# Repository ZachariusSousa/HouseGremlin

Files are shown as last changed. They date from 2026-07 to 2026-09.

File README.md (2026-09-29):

# HouseGremlin / Robit

Robit should be built as two cooperating codebases:

- **Robot firmware**: runs on the ESP board, drives motors/servos, exposes status/camera HTTP plus a persistent control socket, and stays responsive.
- **PC brain**: runs on your computer, handles camera streaming, LLM/tool calling, speech, logging, and higher-level autonomy.

Do not put vision or LLM work on the motor controller. Keep the robot firmware boring and real-time-ish; offload expensive work to the PC.

## Naming

- **HouseGremlin** = this repository / the overall project brand.
- **Robit** = the physical robot (firmware, mDNS `robit.local`, `ROBIT_*` env vars).

## Repo Layout

| Path | What it is | Runs standalone? |
|---|---|---|
| `brain/` | FastAPI PC service: talks to the robot, owns LLM/vision/speech/autonomy | needs robot + LLM |
| `tracking/` | RF-DETR Nano person-detector sidecar (port 8091) | needs GPU, no robot |
| `memory/` | SQLite knowledge graph + ingestion driver + web researcher (port 8092) | Python only |
| `web_control/` | Browser control panel (served by the brain) | — |
| `firmware/robit_controller/` | ESP32 firmware: motors, head, camera, control socket | on the robot |
| `Scripts/` | Cross-package glue: `supervisor.py`, `setup.bat`, `run.bat` | — |
| `cad/` | Printable model (Maindesign.stl) | — |
| `docs/architecture.md` | What talks to what, and why | — |

Port map: **8080** brain · **8081** llama-server (Gemma LLM) · **8091** tracking ·
**8092** memory · **8093** Bekko embeddings. Each package has its own `.venv`,
`requirements.txt`, and `.env.example`; start with the per-package README.

```text
                 ┌──────────────┐  TCP 82 (control)   ┌─────────────┐
 camera stream ─▶│    brain     │◀───────────────────▶│ Robit ESP32 │
   (from robot)  │    :8080     │                     │  firmware   │
                 └──┬───────┬───┘                     └─────────────┘
        HTTP 8091   │       │  OpenAI-compat 8081 / 8093
                    ▼       ▼
             ┌──────────┐  ┌──────────────────────────┐
             │ tracking │  │ llama-server (Gemma LLM) │ + Bekko embeds
             └──────────┘  └──────────────────────────┘
                 memory (:8092) is standalone — ingests brain telemetry,
                 runs the web researcher; nothing else depends on it.
```

`Scripts/supervisor.py` launches brain + tracking + both model servers together;
`memory/` runs on its own (`memory/.venv/Scripts/python -m memory.app.cli`).

## First Build Path

1. Flash `firmware/robit_controller/robit_controller.ino`.
2. Edit Wi-Fi credentials in `firmware/robit_controller/config.example.h`, save as `config.h`, and keep it private.
3. Deploy the matching Brain and confirm its `/robot/*` controls work.
4. Run the PC brain and point it at the robot IP.
5. Add camera streaming.
6. Add LLM tool calling against the PC brain API, not directly against the microcontroller.

## Windows Quick Start

Install 64-bit Python 3.13, then open PowerShell in this folder and run:

```powershell
.\setup
```

## Start

```powershell
.\run
```

When Robit is ready, open [http://localhost:8080](http://localhost:8080) to
use the control panel.

## Stop

Press `Ctrl+C` in the PowerShell window running Robit for a clean shutdown.
If an earlier stack was interrupted, run this from another PowerShell window:

```powershell
.\stop
```

## Robot interfaces

The firmware HTTP server exposes diagnostics and camera access only:

- `GET /status`
- `GET /api/status`
- `GET /camera`
- `GET /camera/capture`
- `GET /camera/stream` is a legacy alias for the still-capture endpoint on port `81`

Actuation uses protocol v1 on TCP port `82`. It is single-client, newline-delimited
JSON with a 512-byte limit, acknowledgements, TTL/sequence rejection, a one-second
PC heartbeat, and firmware telemetry. Direct ESP movement/head/eyes HTTP routes
were intentionally removed; use the stable Brain `/robot/*` API.

All camera acquisition is serialized and capped globally at 2 FPS
(`ROBIT_CAMERA_MAX_FPS=2`). The Brain shares one raw JPEG, rotated JPEG, and
preview for each frame. Idle acquisition is 0.2 FPS.

The XIAO ESP32S3 Sense camera page and still endpoint are:

```text
http://ROBOT_IP/camera
http://ROBOT_IP:81/capture
```

Current soldered pin assumptions:

- `D0` left forward, `D1` left reverse
- `D2` right forward, `D3` right reverse
- `D4` shared PWM for both motor-driver PWM inputs
- `D6`/`D7` PCA9685 servo I2C
- `D5`/`D8` reserved for the OLED eye I2C bus

## Brain

The PC service owns everything above the robot's HTTP/sockets layer: camera
capture and streaming, OpenAI-compatible LLM tool calling, realtime voice
(Parakeet STT / Qwen TTS sidecar), scripted behaviors, telemetry logging, and
the person-tracking controller that consumes `tracking/` detections.

See [docs/architecture.md](docs/architecture.md) for the current architecture and
[DESIGN.md](DESIGN.md) for the long-term Robit design roadmap.

Text and the language step in realtime Voice use one local Gemma 4 E4B
`llama-server`; structured Vision currently reuses it as well. Parakeet STT and
Qwen TTS remain separate voice models, and the Vision adapter remains replaceable
by a dedicated detector or VLM later. Install the validated shared environment
with:

```powershell
.\Scripts\setup.bat
```

The current Gate 5 surface is `GET /perception/latest` plus
`POST /perception/query`. Visual results are descriptive only and cannot issue
movement or head commands in the same turn.

RF-DETR Nano runs in its own `tracking\.venv`, so its Transformers 5
dependency cannot alter the validated voice environment. It powers one simple
always-on person tracker: Robit turns its head toward the visible person and
uses a delayed, bounded in-place body turn only when the head cannot keep up.
RF-DETR runs at 2 FPS while searching, 1 FPS on a stable target, and 0.5 FPS
during voice activity. Tracking starts with Robit and remains off only after an
explicit tracking stop. It does not replace semantic E4B scene descriptions and
it never retains routine camera frames. The tracking API is:

```text
GET  /tracking/status
POST /tracking/start
POST /tracking/stop
```

After `run.bat` is running, verify the default:

```powershell
Invoke-RestMethod http://localhost:8080/tracking/status
```

If tracking was explicitly stopped, turn it back on with:

```powershell
Invoke-RestMethod -Method Post `
  -Uri http://localhost:8080/tracking/start `
  -ContentType "application/json" `
  -Body '{}'
```

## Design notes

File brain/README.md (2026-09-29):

# Brain

This service runs on your computer and owns Robit's coordinator and safety layer: conversation state, event journaling, camera proxying, robot commands, typed and realtime LLM actions, arbitration, and logs.

The realtime speech server runs as a sidecar process, but it uses the same `brain\.venv` as the rest of the project.

## Prerequisites

- Python 3.13 for the shared `brain\.venv`
- `llama-server` from [llama.cpp](https://github.com/ggml-org/llama.cpp/releases) for the shared Gemma 4 E4B language backend
- NVIDIA GPU recommended for local realtime speech

## Run

From the repository root, run setup once:

```powershell
cd C:\Users\z1sou\HouseGremlin
Scripts\setup.bat
```

Then start Robit:

```powershell
Scripts\run.bat
```

The same setup command installs the validated dependencies used by voice and
structured vision. Vision reuses the realtime Gemma 4 E4B server; there is no
second vision-model download.

```powershell
.\Scripts\setup.bat
```

If omitted, `Scripts\run.bat` discovers Robit's current address from its mDNS
name, `robit.local`. This works independently of Windows' normal DNS resolver.

`setup.bat` creates one virtual environment at `brain\.venv` and installs both PC brain and realtime voice dependencies there.
`run.bat` invokes a supervisor that starts one two-slot Gemma 4 E4B `llama-server` for Text, the Voice
language step, and the current Vision adapter. It then starts the separate
Parakeet STT and Qwen TTS voice sidecar from the shared venv, starts the PC
brain in readiness order, and opens the browser UI. Failed sidecars restart up
to three times with bounded backoff. Rotating logs are stored in
`brain\data\logs`. Ollama is not required.

To test realtime voice without the browser:

```powershell
cd C:\Users\z1sou\HouseGremlin
Scripts\voice_test.bat
```

This starts the realtime sidecar, connects a terminal mic/speaker client to `ROBIT_REALTIME_WS_URL`, and exits with `Ctrl+C`.

Manual PC brain setup, if you need to debug it directly:

```powershell
cd C:\Users\z1sou\HouseGremlin\brain
py -3.13 -m venv .venv
.\.venv\Scripts\Activate.ps1
python -m pip install --upgrade pip
python -m pip install -r requirements.txt
```

Manual realtime sidecar run, if you need to debug it directly:

```powershell
cd C:\Users\z1sou\HouseGremlin\brain
.\.venv\Scripts\Activate.ps1
$env:OPENAI_API_KEY="local"
$env:OPENAI_BASE_URL="http://127.0.0.1:8081/v1"
llama-server -hf ggml-org/gemma-4-E4B-it-GGUF:Q4_0 --host 127.0.0.1 --port 8081 -np 2 -c 65536 -fa on --swa-full --reasoning off --image-max-tokens 140
```

In another PowerShell window:

```powershell
cd C:\Users\z1sou\HouseGremlin\brain
.\.venv\Scripts\Activate.ps1
$env:OPENAI_API_KEY="local"
$env:OPENAI_BASE_URL="http://127.0.0.1:8081/v1"
python -m speech_to_speech.s2s_pipeline --mode realtime --ws_host 0.0.0.0 --ws_port 7861 --stt parakeet-tdt --parakeet_tdt_model_name nvidia/parakeet-tdt-0.6b-v3 --parakeet_tdt_device cuda --parakeet_tdt_compute_type float16 --llm_backend responses-api --model_name ggml-org/gemma-4-E4B-it-GGUF:Q4_0 --responses_api_api_key local --responses_api_base_url http://127.0.0.1:8081/v1 --responses_api_request_timeout_s 180 --tts qwen3 --qwen3_tts_model_name Qwen/Qwen3-TTS-12Hz-1.7B-CustomVoice --qwen3_tts_device cuda --qwen3_tts_speaker serena
```

`run.bat` resolves `robit.local` through mDNS service discovery and passes the
current IP to the PC brain internally. Use a numeric argument only for recovery
or diagnostics.
Text mode, the language step in realtime Voice, and the current structured
Vision adapter share one `ggml-org/gemma-4-E4B-it-GGUF:Q4_0` llama.cpp process
at `http://127.0.0.1:8081/v1`. Voice still uses its own Parakeet STT and Qwen
TTS models. Vision remains behind `VisionService` and its own
`ROBIT_VISION_MODEL`/`ROBIT_VISION_BASE_URL` settings so it can move to a
dedicated detector or VLM later without changing Text or Voice.
LLM-issued movement defaults to `ROBIT_LLM_DEFAULT_SPEED=170`, is clamped by
`ROBIT_LLM_MAX_SPEED=180`, and is limited by `ROBIT_LLM_MAX_DURATION_MS=1000`.
The Brain is the only control producer. It connects to firmware protocol v1
on TCP port 82 and coalesces tracking head targets to at most 4 Hz. Manual head
control may run at 10 Hz and leases the actuators for three seconds before
tracking discards its old target and reacquires.

## Checks

From the repository root:

```powershell
.\brain\.venv\Scripts\python.exe -m compileall brain\app brain\tests
.\brain\.venv\Scripts\python.exe -m pytest brain\tests
```

From inside `brain`:

```powershell
python -m compileall app tests
python -m pytest tests
```

## Endpoints

- `GET /health`
- `GET /robot/status`
- `GET /robot/camera`
- `GET /robot/camera/capture`
- `GET /perception/latest`
- `POST /perception/query`
- `POST /robot/drive`
- `POST /robot/head`
- `POST /robot/stop`
- `POST /robot/action`
- `POST /chat`
- `POST /chat/action`
- `GET /brain/state`
- `GET /brain/events`
- `WS /v1/realtime`
- `GET /tools`

The realtime voice sidecar remains separate at `ROBIT_REALTIME_WS_URL`, defaulting to `ws://localhost:7861/v1/realtime`, but it is private to `brain`. The browser connects to the brain gateway at `WS /v1/realtime`.

## Operator Console

The console shows the shared low-rate robot camera, structured scene awareness,
robot telemetry, silent Text mode, realtime Voice mode, manual controls, and an
action log. Text mode calls `/chat/action`; Voice mode streams mic audio to
`brain`, which owns the sidecar session and executes `robot_action` and the
read-only `inspect_scene` tool server-side. Vision cannot authorize movement in
the same turn.

Quick endpoint checks:

```powershell
Invoke-RestMethod http://localhost:8080/health
Invoke-RestMethod http://localhost:8080/robot/status
Invoke-RestMethod http://localhost:8080/robot/camera
Invoke-RestMethod http://localhost:8080/brain/state
Invoke-RestMethod http://localhost:8080/perception/latest
Invoke-RestMethod http://localhost:8080/perception/query `
  -Method Post `
  -ContentType "application/json" `
  -Body '{"question":"What do you see?","fresh":true}'
Invoke-RestMethod "http://localhost:8080/brain/events?conversation_id=default&after_sequence=0&limit=100"
Invoke-WebRequest http://localhost:8080/robot/camera/capture -OutFile $env:TEMP\robit.jpg
Invoke-RestMethod http://localhost:8080/robot/action `
  -Method Post `
  -ContentType "application/json" `
  -Body '{"movement":{"direction":"forward","speed":120,"duration_ms":300}}'
```

Test silent typed chat/action:

```powershell
Invoke-RestMethod http://localhost:8080/chat/action `
  -Method Post `
  -ContentType "application/json" `
  -Body '{"text":"Say hello in one short sentence.","conversation_id":"default"}'
```

Capture Gate 1 realtime latency and GPU usage after the stack is ready:

```powershell
cd C:\Users\z1sou\HouseGremlin
.\brain\.venv\Scripts\python.exe .\Scripts\benchmark_gate1.py
```

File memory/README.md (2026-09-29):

# memory — knowledge-graph memory

SQLite-backed knowledge graph for HouseGremlin's autonomous agents: entity/fact
nodes, typed edges, provenance, FTS5 + optional-embedding hybrid search, and
LLM-routed retrieval with trace logging. The service runs on port **8092**
(ports: 8080=brain, 8081=llama-server, 8091=tracking, 8092=memory).

Phase history and design decisions: `TODO.md`, `Plan.md`. Repo-level rationale:
`DESIGN.md` → "Memory Design" (note the deliberate pivot from "RAG before
GraphRAG" for this component).

## Quickstart

```powershell
# from repo root C:\dev\HouseGremlin
.\memory\.venv\Scripts\python.exe -m pip install -r memory\requirements.txt

# tests (fully mocked LLM; no network, no live model)
.\memory\.venv\Scripts\python.exe -m pytest memory/tests -q

# seed the demo corpus (idempotent sky-is-blue causal chain + distractors)
.\memory\.venv\Scripts\python.exe -m memory.app.cli seed

# start the service on 8092
.\memory\.venv\Scripts\python.exe -m uvicorn memory.app.main:app --port 8092
```

If no embedding endpoint is reachable, the service degrades to FTS5-only mode
and `GET /health` reports `"embedding_mode": "fts5_only"`. If the chat LLM is
down, retrieval degrades to seed-only context with a warning; ingest endpoints
return 503.

## Service (port 8092)

| Endpoint | Body | Returns |
| --- | --- | --- |
| `GET /health` | — | `{"status": "ok", "embedding_mode": "hybrid" \| "fts5_only"}` |
| `GET /stats` | — | node/edge/provenance counts |
| `POST /facts` | `{text, confidence?, source_kind?, source_ref?}` | `{node_id, verdict}` (`duplicate` / `related` / `contradiction` / `new`) |
| `POST /ingest/text` | `{text, confidence?, source_kind?, source_ref?}` | extraction summary (all-or-nothing; 422 on invalid LLM output) |
| `POST /ingest/url` | `{url, confidence?}` | extraction summary (502 on fetch failure) |
| `POST /retrieve` | `{question, max_hops?, beam?}` | `{context, nodes[], trace_id, seed_ids, visited_ids, decisions, ...}` |
| `GET /traces/{id}` | — | full `retrieval_traces` row (seeds, per-hop decisions, rendered context) |

Every `POST /retrieve` writes a `retrieval_traces` row — training data for the
future learned router.

## Environment variables (`MEMORY_*`)

| Variable | Default | Meaning |
| --- | --- | --- |
| `MEMORY_PORT` | `8092` | service port |
| `MEMORY_DB_PATH` | `memory/data/memory.db` | SQLite path (relative paths resolve under `memory/`) |
| `MEMORY_LLM_BASE_URL` | `http://127.0.0.1:8081/v1` | OpenAI-compatible chat endpoint |
| `MEMORY_LLM_MODEL` | `ggml-org/gemma-4-E4B-it-GGUF:Q4_0` | model name passed to the LLM |
| `MEMORY_LLM_TIMEOUT` | `30.0` | per-request timeout (seconds) |
| `MEMORY_CONTEXT_BUDGET_CHARS` | `6000` | hard rendered-context budget; lowest-relevance nodes are dropped until under budget |
| `MEMORY_MAX_HOPS` | `3` | default hop-router depth |
| `MEMORY_BEAM` | `6` | default candidate beam width |

## Agent usage example

```powershell
# remember a fact (dedup/merge/contradiction judged by the LLM, never silent overwrite)
curl -s -X POST http://127.0.0.1:8092/facts -H 'Content-Type: application/json' `
  -d '{"text": "The greenhouse thermostat is on the north wall.", "source_kind": "agent", "source_ref": "conv-42"}'

# retrieve routed context for a question
curl -s -X POST http://127.0.0.1:8092/retrieve -H 'Content-Type: application/json' `
  -d '{"question": "why is the sky blue"}'
```

The `context` string is pre-rendered, budget-bounded text (node sentences with
edge-type annotations) safe to paste into a prompt. `nodes[]` carries ids,
kinds, and hop depths if you need structured access; `trace_id` links back to
the logged traversal.

## CLI walkthrough

All commands run as `.\memory\.venv\Scripts\python.exe -m memory.app.cli <cmd>`:

| Command | Purpose |
| --- | --- |
| `add-fact TEXT [--confidence F] [--source-kind K] [--source-ref R]` | add one canonical fact node with provenance |
| `ingest-text TEXT [--confidence F]` | LLM-extract triples/facts from raw text (all-or-nothing) |
| `ingest-url URL [--confidence F]` | web search + fetch + extract (per-URL cache, skip-and-continue) |
| `seed` | idempotently load the sky-is-blue demo corpus |
| `retrieve QUESTION [--max-hops N] [--beam N]` | routed retrieval; prints context + trace summary |
| `inspect NODE_ID` | show a node with its edges and provenance |
| `forget NODE_ID` | delete a node and cascade its edges/provenance/FTS rows |
| `stats` | node/edge/provenance counts |
| `health` | health + embedding mode |
| `rebuild` | re-sync the FTS5 index from source rows |
| `export-traces --out PATH [--format jsonl\|csv]` | export `retrieval_traces` for offline analysis/training |

## Retrieval model

1. **Seeds** — question tokens (stopwords filtered) hit the FTS5 external-content
   table; when embeddings are available, cosine-similar nodes are added. Both
   score lists are fused with reciprocal-rank fusion into top-k entrance nodes.
2. **Hop router** — up to `max_hops` (default 3) LLM hops: candidates are typed
   edge neighbors of the visited set plus embedding-similar unvisited nodes
   (beam ≤ 6). The LLM returns strict JSON: chosen candidate ids with one-line
   reasons, or `stop`.
3. **Context assembly** — visited nodes ordered by hop/relevance, rendered as
   compact text blocks, then trimmed from the lowest-relevance end until under
   `MEMORY_CONTEXT_BUDGET_CHARS` (hard budget).

Contradictory facts coexist: a `contradiction` verdict links both fact nodes
with `contradicted_by` edges and keeps both active — age never lowers
confidence.

## Evaluation groundwork

- `evals/questions.json` — 12 curated questions over the seed corpus (single-hop
  and multi-hop).
- `app/eval.py` — harness stub: scores returned context against expected key
  facts for LLM-router vs learned-router A/B. The learned side is a documented
  `NotImplementedError` placeholder until traces accumulate and a model is
  trained (`export-traces` feeds that pipeline).

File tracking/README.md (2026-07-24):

# Robit RF-DETR sidecar

This local-only service keeps RF-DETR and its Transformers 5 dependency out of
the voice environment. It accepts shared broker JPEGs and returns only `person`
detections. It does not retain images.

The default `ROBIT_TRACKING_DEVICE=auto` selects CUDA/BF16 when supported and
otherwise runs on CPU. Model-load failures leave the service available for
health checks while `/detect` returns a clear `503`.

To force CPU for one run from PowerShell:

```powershell
$env:ROBIT_TRACKING_DEVICE = "cpu"
.\Scripts\run.bat
```

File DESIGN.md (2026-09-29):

# Robit Future Design Roadmap

This document describes the long-term direction for Robit's brain, perception,
memory, personality, tools, and autonomy. It is intentionally forward-looking.
For the architecture that exists today, see
[`docs/architecture.md`](docs/architecture.md).

The roadmap uses capability gates instead of dates. Work should advance only
after the preceding capability is reliable enough to build on.

## Vision

Robit should grow into a small room-scale companion that can converse, notice
its surroundings, remember useful things, perform approved routines, wander
silently, and research difficult questions in the background.

The target is a hybrid system:

- The ESP remains a deterministic body controller for motors, servos, eyes,
  bounded movement, and disconnect watchdogs.
- A Windows home server is the authoritative brain for speech, perception,
  memory, planning, tools, and autonomy.
- Robit remains useful offline. Internet research is optional and explicit.
- A fast speaking model handles conversation while a larger thinking model
  handles slower planning and research.
- Vision produces a compact structured world state instead of sending a
  continuous stream of image tokens to the conversation model.
- MCP tools are mediated by permissions and policy rather than exposed directly
  to a model.

The current RTX 4090 Laptop GPU with 16 GB VRAM is the development and
benchmarking system. A dedicated always-on Windows server can be chosen later
from measured resource requirements.

## System Shape

```mermaid
flowchart LR
    Mic["Microphone / Wake Word"] --> Voice["VAD -> STT"]
    Camera["ESP Camera"] --> Perception["Frame Gate -> Semantic VLM"]
    UI["Operator Console"] --> Brain

    Voice --> Brain["brain Cognitive Runtime"]
    Perception --> World["Rolling World State"]
    World --> Brain

    Brain --> Speaker["Fast Speaker"]
    Brain --> Thinker["Background Thinker"]
    Brain --> Affect["Tiny Affect Model"]
    Brain <--> Memory["Events + Hybrid RAG"]
    Brain <--> Broker["MCP Capability Broker"]
    Brain --> Executive["Deterministic Executive"]

    Affect --> Eyes["Eye Animation Controller"]
    Speaker --> TTS["TTS"]
    Thinker --> Jobs["Durable Research Jobs"]
    Executive --> Policy["Action Policy + Arbitration"]
    Broker --> Policy
    Policy --> ESP["ESP Safety Layer"]
    ESP --> Body["Tracks / Head / Eyes"]
```

`brain` should remain a modular Python application while the system is
small. Its interfaces should be compatible with a later ROS 2 bridge, but ROS 2
should not be an early dependency.

## State and Arbitration

Do not model Robit with a single thinking/speaking flag. Maintain four related
state planes:

- **Conversation:** `idle`, `listening`, `formulating`, `speaking`, or
  `interrupted`.
- **Body activity:** `stationary`, `looking`, `wandering`, `executing_skill`, or
  `fault`.
- **Background jobs:** zero or more `queued`, `running`, `needs_input`,
  `completed`, `failed`, or `cancelled` tasks.
- **Affect:** a slow-changing mood plus a fast expression overlay.

This allows Robit to wander silently while research runs, stop when addressed,
acknowledge a difficult question immediately, and report the result later.

Arbitration priority is fixed:

1. Hardware faults, firmware watchdogs, and movement limits.
2. Active voice and user interruption.
3. User language responses.
4. Explicit visual requests.
5. RF target reacquisition.
6. Background awareness and follow-ups.
7. Idle curiosity and wandering.

Tracks should normally stop when Robit begins listening or speaking. Head and
eye gestures may continue. Internal reasoning is never automatically spoken.

## Model Roles

| Role | Initial direction | Output | Authority |
| --- | --- | --- | --- |
| Speaker | Keep `gemma4:e4b` initially | Short response, delegation request, proposed tool intent | No direct execution |
| Thinker | Benchmark a larger 16 GB-capable reasoning model | Sourced research artifact or multi-step plan | No audio or motor access |
| Affect | Start with a CPU-hosted tiny text model | Valence, arousal, stance, confidence | Eyes only |
| Vision | Reuse Gemma 4 E4B through local llama.cpp | Typed scene snapshot | No actuation |
| Executive | Deterministic Python behavior code | Approved skills and schedules | May request body actions through policy |
| Retrieval | Local embedding model plus lexical search | Ranked memory references | Read-only |

Model names other than the existing `gemma4:e4b` are candidates, not permanent
commitments. Each role should have a versioned evaluation set so a model is
changed only when a replacement measurably improves Robit's real workload.

### Speaker and thinker

The speaker owns latency, personality, turn-taking, and verbalization. It may
answer directly, request a safe tool, or delegate work. The thinker runs as a
background job and returns a sourced result to the cognitive runtime. It never
speaks or moves the robot directly.

When delegation is needed, Robit should acknowledge it in one short sentence,
continue normal interaction, and proactively report the result when it is ready.
The foreground speaker reformulates that result in Robit's normal voice.

### Affect and eyes

The affect model should receive the latest user utterance, Robit's planned
reply, the dialogue act, current cognitive state, and previous mood. Its output
is a bounded schema containing:

- mood label
- valence
- arousal
- confidence
- requested expression
- expression lifetime

It never receives motor, memory-write, or MCP authority. Operational truth wins
over emotion: listening, thinking, and fault states cannot be hidden
by a cheerful classification.

Firmware should own fixed animations such as `neutral`, `listening`,
`thinking`, `speaking`, `curious`, `pleased`, `excited`, `concerned`, `sleepy`,
`startled`, and `fault`. Mood changes slowly, expression overlays change
quickly, and hysteresis prevents flickering.

## Core Data Contracts

All model-produced control data should use constrained JSON schemas and Pydantic
validation. Invalid output is logged and rejected; it is never partially
executed.

- **`BrainEvent`:** ID, event type, timestamp, source, correlation ID, priority,
  and payload.
- **`CognitiveState`:** conversation state, body state, active goal,
  connectivity, safety state, affect, and attention target.
- **`AffectState`:** label, valence, arousal, confidence, expression, and expiry.
- **`SceneSnapshot`:** frame ID, observation time, summary, entities, bounding
  boxes, novelty, and uncertainty.
- **`TaskRecord`:** task kind, requester, status, progress, approval state,
  result reference, error, and timestamps.
- **`MemoryFact`:** subject, predicate, object, source event, confidence,
  visibility, timestamps, and optional expiry.
- **`ActionIntent`:** skill, arguments, reason, origin, deadline, risk tier, and
  approval requirement.
- **`ToolCapability`:** MCP server, tool, scopes, side effects, risk tier,
  timeout, and concurrency limit.

Existing endpoints should remain compatible while being routed through the
coordinator. The planned interface includes:

- `WS /v1/realtime`
- `GET /brain/state`
- `GET /brain/events`
- `GET /perception/latest`
- `GET /tasks`, `POST /tasks`, and `POST /tasks/{id}/cancel`
- `GET /memories`, `POST /memories`, and `DELETE /memories/{id}`
- `GET /approvals` and `POST /approvals/{id}/decision`
- `POST /robot/eyes`
- firmware `POST /api/eyes`

The browser should become a transport and visualization client. It should not
execute model-selected tools or hold MCP credentials.

## Memory Design

Robit should have four memory layers:

- **Working memory:** recent dialogue and current world state, expiring within
  minutes.
- **Episodic memory:** summarized interactions and notable events.
- **Semantic memory:** durable people, preferences, places, commitments, and
  facts.
- **Procedural memory:** reviewed routines and executable skills.

SQLite in WAL mode should be the source of truth for events, facts, entities,
relationships, tasks, approvals, and artifacts. SQLite FTS5 supplies lexical
retrieval. A local vector index supplies semantic retrieval and remains
rebuildable from the source records.

Retrieval should combine lexical score, vector similarity, recency, entity
filters, confidence, and visibility. Every durable memory must retain its
source. Robit should support natural and UI-driven inspection, correction,
forgetting, and export.

Start with one primary-owner profile. Unknown people receive guest behavior and
cannot retrieve private memories. Do not retain continuous camera footage;
store structured notable events and selected frames only when policy allows.

### RAG before GraphRAG

Begin with hybrid retrieval and typed entity/relationship tables. Add a graph
query path only when a curated multi-hop memory test shows hybrid retrieval
missing more than 20 percent of relational answers and a graph prototype
improves accuracy by at least 15 percentage points without adding more than
500 ms to foreground recall.

This keeps graph-shaped data available without paying the indexing and
debugging cost of a full GraphRAG pipeline before the memory corpus justifies it.

**Implemented substrate (2026-09): `memory`.** The first durable-memory
implementation deliberately pivots from pure RAG for this component: `memory`
stores entity/fact nodes with typed edges and provenance, retrieval enters via
hybrid FTS5 + embedding seeds fused by reciprocal-rank fusion, and a bounded LLM
hop router then walks the graph (≤3 hops, beam ≤6) under a hard rendered-context
budget. This is scoped GraphRAG-style traversal, not a full pipeline — no
community summaries, and every hop decision is logged to `retrieval_traces` so
the empirical test above can still be run: the curated multi-hop question set in
`memory/evals/` is scored against expected key facts by the A/B harness in
`memory/app/eval.py`, before or after a learned router replaces the LLM hop.
Gate 4's semantic layer builds on this substrate rather than re-deriving storage
and retrieval.

## Vision Design

The conversation model should not consume every camera frame. The perception
pipeline should:

1. Sample the camera at a low working rate.
2. Reject blurred, duplicate, and unchanged frames.
3. Invoke the VLM for novel frames, explicit visual questions, scheduled
   awareness checks, or executive requests.
4. Convert results into short-lived `SceneSnapshot` records.
5. Merge recent snapshots into a compact `WorldState`.
6. Give the speaker structured facts rather than raw image tokens.

Uncertainty must be explicit, and `unknown` is a valid result. The VLM may
describe and ground the scene but never issue movement commands.

The first evaluation should use 300 to 500 frames from the actual ESP camera
across lighting, blur, empty rooms, people, furniture, and floor obstacles.
Validate the shared Gemma 4 E4B server on grounding, hallucinations, useful
summaries, latency, voice coexistence, and schema compliance. Start at 140
visual tokens and try 70 if the 750 ms p95 target is missed; consider a separate
vision model only if E4B still fails latency or grounded accuracy.

RF-DETR is a Gate 5 follow-up for fast person geometry used by one always-on
person-tracking behavior. It complements rather than replaces the semantic VLM:
RF-DETR supplies short-lived boxes and track observations, while the VLM remains
responsible for scene meaning, explicit visual questions, and structured
`SceneSnapshot` records. The first detector integration stays deliberately
simple: select one configured backend at startup, process only the newest frame
at a bounded cadence, and report unavailable when that backend cannot run. It
does not poll VRAM, dynamically unload models, or switch models based on live
memory readings. Tracking starts with Robit and has no timeout: the head follows
the selected visible person, with short in-place body pivots only when horizontal
error remains large. It stops only on an explicit tracking request.

## MCP and Tool Policy

`brain` should act as the MCP host and capability broker. MCP servers are not
exposed directly to the speaker or thinker.

The first integration wave should cover:

- web research
- weather
- timers and reminders
- notes
- calendar read
- carefully scoped smart-home actions

Risk tiers:

- **Tier 0:** public read-only data; automatic.
- **Tier 1:** local, easily reversible actions such as timers or appending a
  note; automatic but logged.
- **Tier 2:** external writes, messages, calendar changes, or device changes;
  confirmation required.
- **Tier 3:** purchases, locks, deletion, credentials, or broad computer access;
  explicit per-action approval and optionally disabled.

Tool descriptions and results are untrusted data, not system instructions.
Credentials stay server-side and out of prompts, logs, and memory. Servers and
scopes are allowlisted. Every call has a timeout, concurrency limit, output-size
limit, audit event, and cancellation path.

Robit should own a durable internal task system. MCP task support can be adapted
at the protocol boundary without making the core job lifecycle depend on an
evolving external specification.

## Capability-Gated Roadmap

### Gate 0: Restore and measure the current baseline

**Status: functionally closed on 2026-07-14.**

The functional exit condition has been met: the repaired Python 3.11
environment passes all 18 tests, and the real browser UI has completed realtime
voice conversation plus bounded manual and model-requested robot actions. Camera,
text chat, action parsing, and movement safety clamps are working in the current
baseline.

The pan axis has a known mechanical stall under load. Commands reach the shared
manual/AI firmware path correctly, so this is accepted as a chassis or servo
design limitation for Gate 0 rather than an unresolved brain-stack failure. A
bounded-stop and disconnect-watchdog checks must be repeated after any motor,
power, or chassis revision.

- Recreate the stale Python 3.11 virtual environment with the existing setup
  script.
- Verify camera, text chat, realtime voice, manual movement, action parsing,
  safety clamps, ordinary stop, and disconnect stopping.
- Record warm and cold latency, CPU, VRAM, and failure logs for every model
  stage.
- Create a permanent evaluation corpus covering dialogue, tool calls,
  uncertainty, malformed output, interruption, and safety.

Exit when existing tests pass and the real browser UI completes one voice
conversation and one bounded robot action.

Carry the formal warm/cold latency, CPU, VRAM, failure-log capture, and permanent
evaluation corpus into the opening Gate 1 baseline work. These artifacts remain
required before making model or server sizing decisions, but they do not reopen
the functional Gate 0 baseline.

### Gate 1: Make `brain` authoritative

**Status: functionally closed on 2026-07-15.**

The coordinator, SQLite WAL event journal, state planes, correlation tracing,
priority arbitration, foreground resource lease, realtime gateway, reconnect
replay, and server-owned voice tool execution are implemented. The automated
suite passes 49 tests. Live gateway measurements reached first audio in 0.833
seconds on the first session turn and 0.337 seconds warm using `serena`.

The physical acceptance pass is complete. The real browser preserves the active
conversation across reconnects, bounded actions execute on the robot, and each
action can be traced back to its originating request through the shared event
and correlation flow.

- Add the event model, state planes, append-only journal, and priority arbiter.
- Put realtime session ownership behind `brain` while reusing the current
  VAD, STT, and TTS components.
- Move voice tool execution out of browser JavaScript.
- Give foreground work a resource lease that can preempt background GPU jobs.
- Use the same conversation, policy, memory, and event flow for Text and Voice
  modes.
- Carry correlation IDs from utterance through model, tool, firmware, and UI.

Exit when reconnecting the browser preserves the active conversation and every
robot action can be traced to its originating request.

### Gate 2: Implement eyes and affect

**Status: functionally closed on 2026-07-19.**

The physical eye renderer, automatic operational overlays, expression policy,
and heartbeat fault path are sufficient to build on. Affect-set validity,
heartbeat timing, and end-to-end voice/eye latency measurements remain tracked
as Gate 2 follow-up validation and do not reopen the functional gate.

**Early hardware bring-up:** the firmware began with a minimal SSD1306 wiring
test on the shared D6/D7 I2C bus at addresses `0x3C` and `0x3D`. At boot it
briefly illuminated every pixel and then displayed a thick horizontal line.
That test established display wiring and power before the Gate 2 renderer was
implemented.

The fixed expression renderer and firmware `/api/eyes` endpoint are implemented
and physically validated. `brain` now maintains a temporary LLM-selected base
mood beneath deterministic listening, thinking, speaking, and fault overlays.
Eye commands use a latest-value asynchronous queue, and an armed firmware
heartbeat watchdog displays `fault` after twelve seconds without the PC brain.

- Implement the fixed eye animations and firmware `/api/eyes` endpoint.
- Add the affect schema, tiny classifier, mood decay, expression overlays, and
  operational overrides.
- Collect classifications and corrections for later fine-tuning or distillation.
- If the affect model is unavailable, display truthful operational state without
  inventing emotion.

Exit when affect output is valid on at least 99.5 percent of the evaluation set,
never changes tools or movement, and remains visually stable during rapid turns.

### Gate 3: Add autonomous voice presence

**Status: intentionally deferred while Gate 5 vision is implemented.**

- Add a local `Robit` wake word followed by VAD and Parakeet STT.
- Keep room audio at the microphone source until activation.
- Add visible and physical privacy mute states.
- Support barge-in that cancels queued speech and returns to listening.
- Keep Text mode silent and Voice mode spoken.
- Keep internal thoughts and research progress out of spoken output.

Exit when false wakeups are acceptable over several hours of household audio,
barge-in silences playback within 250 ms, and mute prevents capture.

### Gate 4: Add durable hybrid memory

**Status: intentionally deferred while Gate 5 vision is implemented.**

- Implement the working, episodic, semantic, and procedural memory layers.
- Add provenance-aware memory extraction and hybrid retrieval.
- Add remember, inspect, correct, forget, export, and retention controls.
- Add owner/guest isolation.
- Make the vector index fully rebuildable from SQLite.

Exit when curated recall tests pass, forgetting removes all derived records, and
private memories never appear in guest context.

### Gate 5: Add structured vision

**Status: functionally available as of 2026-07-22; improvements and acceptance
work required before closure.**

The initial software path now includes a mutex-protected firmware-wide 3 FPS
camera ceiling, a shared in-memory PC frame broker, blur/change filtering,
low-rate idle awareness, and fresh read-only visual questions. The broker
returns to 0.2 FPS only while person tracking is explicitly disabled and no
conversation needs a fresh view. Routine camera frames are not retained. E4B
evaluation and physical acceptance remain before Gate 5 closure.

Observed limitations of the current shared-E4B approach:

- Fresh inference has taken about 2.6 seconds in live use, substantially above
  the 750 ms p95 exit target. Explicit questions therefore have a noticeable
  pause, and sharing E4B with foreground conversation remains a contention risk.
- Scene summaries are often generic or lack useful detail. Grounding accuracy,
  entity recall, and hallucination rate have not yet been measured on the
  Robit-camera corpus.
- E4B has produced truncated JSON at the configured output budget. Validation
  correctly rejects it, but the resulting cached fallback can make an answer
  appear stale and the required 99 percent schema-validity rate is unproven.
- Realtime dialogue previously allowed old assistant visual claims to outweigh
  a newer structured snapshot. Visual history is now excluded when a voice
  session is restored, and current snapshots explicitly override earlier scene
  descriptions, but this mitigation needs longer live testing.
- The speech sidecar begins speculative generation as soon as transcription
  completes, which previously let it narrate an inspection without executing
  one. Explicit visual questions now cancel that response, run a fresh
  inspection, and start a grounded response; this is correct but adds latency.
- The PC broker's default 0.2 FPS idle cadence reduces bandwidth and power, but
  a newly changed scene may take up to five seconds to reach ambient context.
  Explicit visual questions and active tracking may request fresher frames up
  to the firmware's global 3 FPS ceiling.
- Schema compliance, physical camera traffic, no-frame-retention behavior, and
  foreground voice responsiveness still need the documented corpus and
  concurrency acceptance runs.

- Implement camera sampling, blur/change filtering, VLM invocation, scene
  snapshots, and rolling world state.
- Validate the shared Gemma 4 E4B backend on the Robit-camera corpus.
- Allow explicit fresh visual queries when cached perception is stale.
- Prevent vision from entering the motor control loop.
- Add RF-DETR person observations for default-on head and body person tracking
  without replacing the VLM semantic lane.
- Keep detector scheduling static and bounded: one configured backend,
  latest-frame-wins processing, bounded detector requests, and no live VRAM
  monitor or dynamic model swapping.

Exit when the chosen VLM processes selected frames within 750 ms at p95 on the
development laptop, reaches at least 99 percent valid structured output, meets
the grounded-description quality target, and does not starve foreground voice.
RF-DETR follow-up acceptance is additional and does not weaken or replace these
semantic-vision exit conditions.

### Gate 6: Add the background thinker

- Introduce durable, cancellable research and planning jobs.
- Delegate when research is requested, current information is required, several
  tools are needed, or the speaker has low confidence.
- Require sourced artifacts with claims, uncertainty, and a speaker-ready
  summary.
- Deliver one proactive follow-up while respecting quiet hours.
- Preempt or pause background inference for foreground voice.

Exit when jobs survive restart, results are source-supported, follow-ups occur
once, and foreground latency remains within budget.

### Gate 7: Add MCP companion tools

- Implement the MCP host, server registry, capability normalization, risk
  policy, approval flow, audit log, and cancellation.
- Add the companion-basics integrations.
- Test prompt injection, credential leakage, confused-deputy behavior, SSRF,
  malicious tool output, and unavailable servers.

Exit when every high-risk mutation requires approval, secrets never enter model
context, and failed tools cannot destabilize conversation or autonomy.

### Gate 8: Add bounded silent autonomy

Initial code-defined skills:

- `look_around`
- `short_wander`
- `investigate_change`
- `greet_visible_person`
- `return_to_idle`
- `sleep`
- `stop`

The model chooses a goal or approved skill, not motor pulses. The executive
expands skills into short bounded actions. New speech, lost connectivity, stale
perception, model failure, ordinary stop, or lost control connectivity cancels motion.

Begin mapless in one controlled flat room at low speed. Gentle furniture contact
is acceptable for the current tiny chassis, but the robot must not roam
unattended near stairs, ledges, heaters, water, or entanglement hazards.

Exit after at least 100 supervised ten-minute trials with no movement surviving
a stop condition and no repeated runaway behavior.

### Gate 9: Build the always-on Windows brain

- Add one PowerShell supervisor with `setup`, `start`, `stop`, `status`,
  `doctor`, `benchmark`, `backup`, and `restore` commands.
- Supervise the brain, model servers, voice adapter, vector index, and MCP
  servers as native Windows processes.
- Add health checks, automatic restart, exact model manifests, backup, and
  restore.
- Test loss of internet, robot Wi-Fi, MCP services, individual model processes,
  and GPU availability.
- Size the future server from measured peak usage plus 30 percent headroom.
- Complete a 72-hour soak test.

Exit when the stack starts after reboot, recovers from individual failures,
remains useful offline, and needs no collection of manually managed terminals.

## Later Expansion Paths

- **Mapping and docking:** add battery telemetry and a visually identifiable
  dock after mapless roaming is reliable. Begin with a marker or beacon; use
  natural visual SLAM only if markers are unacceptable.
- **Onboard companion computer:** add one when wake-word privacy, network-loss
  behavior, or latency cannot be handled at the audio source and ESP layer.
- **GraphRAG:** enable only after the measured relational-recall trigger.
- **ROS 2:** adopt only when mapping, odometry, transforms, multiple sensor
  streams, or Nav2 justify it.
- **Vision-language-action models:** evaluate only after collecting a large
  teleoperation dataset for Robit's exact chassis. They remain behind the normal
  skill and safety layers.
- **Household profiles:** add opt-in voice or face identity after the
  single-owner memory system passes privacy and forgetting tests.
- **Memory consolidation:** use idle time for summarization, contradiction
  detection, fact merging, and decay without inventing memories.
- **Active perception:** allow small head or body adjustments to resolve visual
  uncertainty before asking the VLM again.
- **Learning from demonstration:** convert reviewed manual-control recordings
  into named deterministic skills.
- **Digital twin and replay:** replay events, snapshots, decisions, and firmware
  responses without moving the real robot.
- **Curiosity budget:** eventually add bounded novelty-seeking, social energy,
  and boredom while keeping them subordinate to quiet hours and safety.

## Acceptance Metrics

- Warm end-of-speech to first audio: at most 1.5 seconds at p95.
- Barge-in to playback silence: at most 250 ms.
- Model-proposed physical actions passing schema validation: 100 percent.
- High-risk MCP actions executed without approval: zero.
- Durable memories without provenance: zero.
- Autonomous motion continuing after disconnect or ordinary stop: zero.
- Background work delaying voice because it holds GPU resources: zero.
- Significant events traceable through a single correlation ID: 100 percent.

Maintain versioned evaluation packs for conversation, affect, perception,
memory, tools, research, autonomy, crash recovery, offline operation, and
long-duration resource stability.

## PowerShell Workflow

Run initial setup from the repository root. The setup script detects and
recreates a broken virtual environment:

```powershell
cd C:\Users\z1sou\HouseGremlin
.\Scripts\setup.bat
```

Start the current application with:

```powershell
cd C:\Users\z1sou\HouseGremlin
.\Scripts\run.bat
```

During implementation, use a second PowerShell window for tests and endpoint
checks:

```powershell
cd C:\Users\z1sou\HouseGremlin
.\brain\.venv\Scripts\python.exe -m pytest brain\tests
Invoke-RestMethod http://localhost:8080/health
```

After Gate 1, also inspect the planned coordinator state:

```powershell
Invoke-RestMethod http://localhost:8080/brain/state
```

By Gate 9, the intended operator workflow is:

```powershell
.\Scripts\robit.ps1 doctor
.\Scripts\robit.ps1 start
.\Scripts\robit.ps1 status
.\Scripts\robit.ps1 benchmark
```

These `robit.ps1` commands are part of the future implementation contract; the
script does not exist yet.

## Locked Decisions

- The ESP remains the safety-critical body controller.
- The home-server brain remains Windows-based.
- Core personality, voice, memory, and basic behavior work offline.
- Web research is opt-in.
- The current laptop is the development system; a dedicated server comes later.
- Early autonomy is camera-led, mapless, supervised, and limited to one room.
- `brain` remains modular Python and ROS-ready without adopting ROS 2 now.
- Memory supports one primary owner first and is useful by default with inspect,
  correct, forget, and export controls.
- A dedicated tiny affect model drives emotional eye behavior, with operational
  overrides.
- Mood changes slowly while expressions react quickly.
- Speaking and thinking models are separate.
- Research acknowledges immediately and follows up proactively.
- MCP uses risk-tiered approval.
- `gemma4:e4b` remains the speaker model until a Robit-specific evaluation
  demonstrates a better replacement.

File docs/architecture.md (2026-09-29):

# Robit Architecture

## Recommendation

Build Robit as a distributed system:

```text
Browser / phone
      |
      v
PC brain service  <---- camera / mic / speakers / LLM / tools
      |
      v
ESP robot firmware <---- motors / servos / sensors
```

The ESP should not do vision, LLM calls, speech, or long-running decision logic. It should only do deterministic hardware control and report status. Your PC has the CPU, memory, networking, and storage for everything else.

## Why This Split

The current sketch is a good proof of concept: it starts a Wi-Fi access point, serves a web page, drives the motors, and controls the pan/tilt head. The problem is that it mixes UI, networking, and hardware control in one file. That is fine for testing, but it will get painful once you add camera streaming, autonomous behaviors, and LLM tool calling.

The next version should keep firmware small:

- receive commands
- clamp unsafe values
- stop motors if commands stop arriving
- expose status
- optionally read simple sensors later

The PC brain should handle:

- camera stream ingestion
- object/person detection
- speech-to-text and text-to-speech
- LLM conversation state
- tool calling
- route planning or behavior scripts
- logs and debugging UI

## Networking

Support both modes:

1. **Station mode**: Robit joins your home/dev Wi-Fi. This is the normal mode when the PC brain controls it.
2. **Fallback access point**: Robit creates `Robit-Control` if it cannot join Wi-Fi. This is useful for setup and recovery.

The firmware scaffold implements that pattern.

## Control API

Keep the robot interfaces boring. HTTP is diagnostic-only:

```text
GET /status
GET /api/status
GET /camera
```

All actuation uses the single-client NDJSON protocol v1 socket on TCP port 82.
The PC `ActuatorBroker` is the only producer. Sequence, TTL, acknowledgement,
heartbeat, and telemetry handling live at this boundary; body commands never
replay after reconnect.

## Camera

The camera is the built-in XIAO ESP32S3 Sense camera. Firmware serializes all
`/capture` acquisition through one mutex and enforces a global 2 FPS ceiling.
The legacy `/stream` URL redirects to one still capture so it cannot monopolize
the firmware's small HTTP server. The PC brain's in-memory `FrameBroker` controls demand
independently: it defaults to 0.2 FPS while idle and raises the request rate only
when tracking or conversation needs a fresher view. Person tracking is enabled
by default, so the low idle rate applies only after tracking is explicitly
disabled. Each acquired frame is shared with the browser, detector, and
perception pipeline. Routine frames are never written to disk.

## Structured Vision

`VisionService` rotates camera frames into their displayed orientation, rejects
blurred or unchanged 160x120 previews, and runs background awareness no more
than once every 30 seconds while conversation is idle. Valid VLM JSON becomes
a short-lived `SceneSnapshot`; snapshots from the last minute form `WorldState`.
The service sends selected frames to the existing Gemma 4 E4B llama.cpp server,
requests JSON-schema output, and disables itself cleanly if `/v1/models` does
not advertise multimodal image support. The shared server runs with reasoning
disabled so short voice and scene responses do not spend their latency budget
on hidden reasoning tokens. Text and the Voice language step also use this one
two-slot E4B process; the audio pipeline still has separate Parakeet STT and Qwen
TTS models. Vision keeps an independent adapter and configuration boundary so a
dedicated VLM can replace E4B later without changing Text or Voice.

Text and Voice can request a fresh read-only inspection through the PC brain.
The latest unexpired validated snapshot is also injected into every Text and
Voice model turn as live visual context. Awareness refreshes that context when
the scene changes and carries it forward across pixel-equivalent frames without
rerunning the VLM.
The same turn cannot use a vision result for movement or head control. Ordinary
stop, bounded movement duration, and link-loss stopping remain available.
`GET /perception/latest` is the browser's
scene-state feed and `POST /perception/query` forces an explicit inspection.

Gate 5 is functionally available but not accepted as complete. Live testing has
shown roughly 2.6-second fresh-inference latency, generic scene descriptions,
occasional truncated structured output, and stale visual claims from realtime
dialogue history. The gateway now removes superseded visual dialogue when it
restores a session, makes current snapshots override earlier descriptions, and
cancels speculative speech before answering an explicit visual question from a
fresh validated result. These mitigations preserve correctness but do not solve
the remaining latency and description-quality limits. The broker's 0.2 FPS idle
default intentionally permits up to five seconds of ambient-view delay, while
active tracking or conversation can request fresher frames up to the firmware's
2 FPS ceiling. Corpus, schema-validity, voice-concurrency, physical traffic, and
retention acceptance tests remain required before the gate is closed.

### Companion Person Tracking

RF-DETR is a Gate 5 follow-up that adds fast person boxes and short-lived track
observations for one always-on behavior. Robit turns its head toward the selected
visible person and uses a proportional in-place body turn when horizontal error remains
large for 1.5 seconds. RF-DETR runs at 2 FPS while acquiring, 1 FPS while
stable, and 0.5 FPS during voice activity. The behavior starts with Robit and
stops only after an explicit tracking request. It is not a VLM replacement. The VLM
continues to answer semantic visual questions and produce `SceneSnapshot`
records; RF-DETR only supplies the geometry used by this deterministic behavior.

The first implementation intentionally avoids a VRAM monitor or dynamic model
swapping. One detector backend is selected from configuration at startup, one
latest-frame-wins worker runs at a bounded cadence, and detector request
timeouts report the detector unavailable cleanly if inference cannot keep up.
This keeps CPU-only community builds understandable and prevents
hardware-specific resource policy from entering the safety path.

The control API is deliberately small:

```text
GET  /tracking/status
POST /tracking/start       {}
POST /tracking/stop        {}
```

The browser exposes one enabled checkbox and one status line. The camera proxy
returns `X-Robit-Frame-Id`; its optional target overlay is drawn only when that
exact ID matches `target.frame_id` from tracking status. A stale box is therefore
never painted over a newer frame.

## LLM Tool Calling

The LLM should call PC-side tools like:

- `drive(move, duration_ms)`
- `set_head(pan, tilt)`
- `look_for(object_name)`
- `speak(text)`
- `stop()`

Those tools should call the robot API or local camera/speech modules. The LLM should not directly hit firmware endpoints; keep a safety layer in the PC brain.

## Memory Service (standalone)

`memory/` is a self-contained service on port **8092** — nothing else depends on it,
so it runs in its own venv and can be developed without the robot. It owns:

- **Knowledge graph** — SQLite entity/fact nodes, typed edges, provenance, FTS5 +
  optional Bekko-embedding hybrid search, LLM-routed retrieval with traces.
- **Ingestion driver** (`watch-brain`) — tails the brain's telemetry journal and
  extracts durable facts into the graph.
- **Web researcher** (`research` / `watch-research`) — LLM-driven BFS over the web,
  source-agnostic (ddgs), findings stored with provenance.

It calls the same local Gemma llama-server (8081) and Bekko embed server (8093)
the brain uses; see `memory/README.md` for the CLI and `memory/.env.example`.

## Safety Defaults

The firmware should:

- stop motors on boot
- stop motors on unknown command
- stop motors after a heartbeat timeout
- clamp servo angles
- clamp motor speed

The PC brain should:

- rate-limit movement commands
- prefer short movement durations
- expose a hard stop command
- log autonomous actions

## Build Roadmap

1. **Firmware cleanup**
   - Move credentials to `config.h`
   - Add `/status`
   - Add command timeout
   - Keep fallback AP mode

2. **Manual PC control**
   - Run `brain`
   - Proxy manual commands to the robot
   - Confirm drive/head controls work

3. **Vision**
   - Validate shared E4B p95 latency, schema compliance, and grounding
   - Verify that two llama.cpp slots preserve foreground voice responsiveness
   - Fall back from 140 to 70 visual tokens before considering another model

4. **Voice**
   - Add push-to-talk or wake-word later
   - Start with a simple text chat interface

5. **LLM tools**
   - Add a tool layer in the PC brain
   - Start with safe movement and head-control tools
   - Add vision query tools after camera is reliable

6. **Autonomy**
   - Add scripted behaviors first
   - Let the LLM choose among those scripts
   - Add guardrails before free-form movement

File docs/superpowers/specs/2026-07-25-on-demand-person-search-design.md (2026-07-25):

# On-Demand RF-DETR Person Search Design

## Summary

Replace continuous YuNet/RF-DETR tracking with one explicit, bounded command:
"look at me." Robit searches for at most ten seconds using RF-DETR, stops on
the first valid person detection, and remains facing that general direction
with his head at a fixed head-height pose.

This is a hard cleanup. YuNet, face landmarks, angular gaze correction,
detector comparison modes, and the continuous tracking controller are removed
rather than disabled.

## Behavior

The deterministic text and voice phrases "look at me" and "find me" start one
person search. Only one search may run at a time.

At the start of a search, Robit:

1. Cancels any previous search.
2. Commands the head to pan `90` and tilt `75`.
3. Waits for the head command to complete and for a fresh camera frame.
4. Runs RF-DETR once on that frame.

If RF-DETR returns any person at or above the configured person confidence,
the first returned person wins. Robit sends an ordinary stop command, remains
at the current body orientation and fixed head-height pose, and reports that
he found someone. He does not center the person, publish a corrective head
target, or continue tracking.

If no person is detected, Robit performs one `350` ms right pivot at speed
`140`, waits `500` ms after the bounded movement ends, obtains a frame captured
after settling, and tries RF-DETR again. This repeats until a person is found
or ten seconds have elapsed.

On timeout, Robit sends an ordinary stop command, leaves his head at the
head-height pose, and reports that he could not find anyone. Manual head,
drive, and stop commands cancel an active search before taking control.

## Architecture

### PC Brain

Replace `PersonTrackingService` with a small `PersonSearchService`. It owns
only:

- idle, positioning, detecting, turning, found, timed-out, cancelled, and
  faulted states;
- one active search task;
- the ten-second deadline;
- fresh-frame RF-DETR requests;
- bounded body pivots and settling;
- cancellation generation;
- compact status and command counters.

The service does not maintain a target between frames, estimate velocity,
associate people, predict motion, calculate gaze angles, or run a background
detection loop.

The existing frame broker remains the only source of robot-camera frames.
Search requests ask for a frame newer than the completed head or body command,
so a frame captured during movement cannot authorize success or another turn.

The actuator broker remains the only source of ESP commands. Search pivots use
bounded movement durations. An ordinary stop supersedes movement after a
detection, timeout, cancellation, or fault.

### Tracking Sidecar

The sidecar becomes RF-DETR person-only:

- remove YuNet initialization and inference;
- remove face model asset downloading;
- remove `shadow`, `face_only`, and `person_only` mode selection;
- remove face boxes and landmarks from the response schema;
- retain the existing JPEG request, frame identity checks, person confidence,
  queue timing, inference timing, backend status, and isolated RF-DETR
  dependency.

If OpenCV is no longer used anywhere in the sidecar after cleanup, remove its
dependency and model files.

### Commands and APIs

Deterministic text and realtime voice routing recognize "look at me" and "find
me" and invoke the same search operation. The model does not need to infer a
sequence of turns.

Expose:

- `POST /tracking/look-at-me` to start and await a search;
- `GET /tracking/status` for current state, elapsed time, remaining time,
  attempts, last detection confidence, last error, and command counts.

Remove `/tracking/start`. Keep `/tracking/stop` only as a cancellation alias
for an active search; it does not manage a persistent tracking mode. Existing
manual robot endpoints remain unchanged.

## Configuration

Keep only person-search settings:

- RF-DETR base URL and request timeout;
- person confidence;
- search timeout, default `10` seconds;
- head-height pan, default `90`;
- head-height tilt, default `75`;
- right-pivot speed, default `140`;
- pivot duration, default `350` ms;
- post-command settling interval, default `500` ms.

Remove YuNet confidence, minimum face size, detector mode, camera field of
view, angular gains, angular deadband, continuous detector cadences, face
association timers, and continuous pivot timers.

## Failures and Cancellation

A detector error, camera timeout, rejected actuator command, or control-channel
disconnect ends the search as `faulted`, sends an ordinary stop when the
control channel permits it, and reports the exception class and stage.

Cancellation is generation-based. Results from an older camera request,
detector request, head command, or turn cannot mutate the new search or issue
another actuator command.

Search confirmation is spoken only after the final stop acknowledgement.
Failures and timeouts are reported as failures or timeouts, never as success.

## Observability

Do not store image bytes. Journal one event for search start and one terminal
event for found, timeout, cancelled, or faulted. Each detection attempt emits
a bounded numeric sample containing frame ID, attempt number, person
count, best confidence, detector latency, camera latency, and current search
state.

Health reports RF-DETR availability and latency. Tracking status no longer
contains face geometry, angular calculations, estimator confidence, target
age, or shadow comparison statistics.

## Tests

Tests cover:

- head-height positioning precedes the first detection;
- the first fresh frame containing any person ends the search;
- detection at the edge of the frame causes no centering correction;
- a miss causes one bounded right pivot and a post-settling fresh frame;
- a person found after a pivot causes stop and no further turn;
- timeout occurs within the ten-second bound and stops movement;
- manual head, drive, and stop cancel the search;
- stale results from cancelled searches cannot issue commands;
- only one search runs at a time;
- detector, camera, actuator, and disconnect failures are reported accurately;
- no background detector requests occur while idle;
- the sidecar returns person-only results and has no YuNet/OpenCV model path;
- deterministic text and voice phrases invoke the same operation;
- status and journal samples contain no image bytes.

## Acceptance

From idle, saying "look at me" causes Robit to place his head at the configured
head height and search to the right. He stops on the first RF-DETR person
detection without attempting to center or follow that person. The operation
finishes within ten seconds, remains idle afterward, and sends no further
camera, detector, head, or body tracking commands until another explicit
search request.

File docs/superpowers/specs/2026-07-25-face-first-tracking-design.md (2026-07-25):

# Robit Face-First Tracking Design

## Summary

Replace RF-DETR as Robit's primary gaze sensor with OpenCV YuNet face
detection. YuNet runs on CPU against frames already supplied by the shared
camera broker and publishes face boxes plus five facial landmarks. The
tracking controller aims at the midpoint between the detected eyes rather than
estimating face height from a general person box.

RF-DETR remains temporarily available only as the shadow comparator and
configuration rollback during the trial. It does not participate in normal
face-first control. After YuNet passes physical acceptance, remove RF-DETR and
its PyTorch/CUDA sidecar dependencies. The existing vision-language model
remains responsible for semantic scene and object understanding.

The cutover is gated by a shadow evaluation on actual Robit camera frames.
YuNet is the selected candidate, but it must beat the current tracker on
detection retention, aim-point stability, false positives, latency, and compute
load before it is permitted to control the head.

## Goals

- Keep Robit's visual attention centered on a visible face.
- Reduce GPU contention and detector latency.
- Preserve calm gaze through brief occlusion or head turns.
- React calmly when a face is no longer visible instead of chasing a body.
- Avoid face recognition, identity embeddings, or stored biometric data.
- Keep all routine frames memory-only and use the shared frame broker.
- Preserve the browser-facing tracking API where practical.

## Non-Goals

- Recognizing who a person is.
- Inferring emotion, attention, or intent from facial landmarks.
- Replacing the vision-language model for object or scene understanding.
- Increasing robot camera acquisition above the existing 2 FPS ceiling.
- Allowing raw detector output to control actuators directly.
- Tracking a person whose face is not visible.
- Fine-tuning a face detector before the stock model is evaluated on Robit's
  camera.

## Model Selection

### Selected primary detector: OpenCV YuNet

YuNet is a small ONNX face detector supported by OpenCV's
`FaceDetectorYN`. It returns a face box, confidence, and five landmarks: both
eyes, nose tip, and both mouth corners. The published model is approximately
338 KB. Its paper reports 1.6 ms inference on an Intel i7-12700K at 320x320,
and the OpenCV model documentation describes detection support for faces around
10x10 through 300x300 pixels.

YuNet is preferred because Robit's source frames are low resolution and the
required output is a stable facial aim point. CPU execution also avoids
competing with speech and language/vision workloads on the GPU.

References:

- <https://docs.opencv.org/master/d0/dd4/tutorial_dnn_face.html>
- <https://github.com/opencv/opencv_zoo/tree/main/models/face_detection_yunet>
- <https://link.springer.com/article/10.1007/s11633-023-1423-y>

### Evaluated alternatives

- **MediaPipe BlazeFace:** viable runner-up with six facial points and a
  streaming mode, but its 128x128 detector input is less compelling for
  Robit's small faces. It remains the fallback candidate if YuNet underperforms
  on profile faces in the shadow evaluation.
- **SCRFD:** strong difficult-face accuracy, but the supplied InsightFace model
  weights have non-commercial-research licensing restrictions and add a larger
  runtime surface.
- **MediaPipe Pose Landmarker:** useful for body landmarks, but performs more
  work than gaze requires and is optimized around a sufficiently visible body.
- **RF-DETR Nano:** useful as the current-system shadow comparator, but not
  suited to facial gaze because it returns only general person boxes. It is not
  part of the accepted end-state architecture.

## Architecture

### Detector boundary

Keep detection isolated from PC Brain behind a local sidecar interface. The
sidecar receives a frame ID, capture timestamp, rotated JPEG bytes, and score
threshold. It returns:

```json
{
  "frame_id": "opaque-frame-id",
  "captured_at": "ISO-8601 timestamp",
  "backend": "opencv/yunet/cpu",
  "latency_ms": 4.2,
  "queue_ms": 0.1,
  "faces": [
    {
      "confidence": 0.94,
      "bounding_box": [0.30, 0.18, 0.58, 0.56],
      "right_eye": [0.38, 0.31],
      "left_eye": [0.50, 0.31],
      "nose": [0.44, 0.39],
      "right_mouth": [0.39, 0.47],
      "left_mouth": [0.49, 0.47]
    }
  ]
}
```

All coordinates are normalized to the rotated frame. Results for a different
frame ID or timestamp are rejected. The sidecar does not acquire camera frames,
retain images, recognize identities, or issue actuator commands.

The production detector interface is typed around faces rather than preserving
RF-DETR's person-only response. During the trial, the old RF-DETR adapter
remains isolated behind the existing interface solely for comparison and
rollback. No shared face/person abstraction is added to production merely to
support the temporary migration.

### Tracking controller

The tracking controller is the sole owner of target association, temporal
estimation, gaze publication, and body-pivot authorization.

For a face target:

1. Derive the measured gaze point from the midpoint between the two eye
   landmarks.
2. Reject malformed landmark geometry and faces below the configured minimum
   pixel size.
3. Acquire after two consistent detections within two seconds.
4. Associate by temporal position, box overlap, scale change, and predicted
   motion. Do not use face embeddings.
5. Require three consistently superior detections before switching faces.
6. Feed the gaze point into the existing bounded alpha-beta estimator.
7. Publish desired gaze through the actuator broker using the existing
   deadband, coalescing, and rate limits.

The detector never sends individual servo steps and never authorizes movement
by itself.

### Face-first state flow

The controller tracks both a state and a target source:

```text
face_searching
  -> face_acquiring
  -> face_tracking
  -> face_grace
  -> face_lost
```

- **face_searching:** YuNet runs at 2 FPS. No stale target can move the body.
- **face_acquiring:** two consistent face detections are required.
- **face_tracking:** YuNet runs at 2 FPS initially and may drop to 1 FPS after
  the gaze is stable. Face geometry is authoritative.
- **face_grace:** preserve the last reasonable gaze for up to 2.5 seconds.
  Prediction is capped at 0.5 seconds and does not count as a detection.
- **face_lost:** after the grace period, discard the target and continue YuNet
  searching at 2 FPS without body movement.
- When the face detector returns two consistent observations, face tracking
  reacquires from fresh geometry and discards the old estimator state.
- After five seconds without a face, issue one neutral head target and remain
  in face searching without repeated head or body search movement.

Frames captured during a pivot or settling interval update neither the
face-gaze estimator nor body-movement authorization. The next post-settling
frame establishes a new screen-space estimate.

### Workload behavior

- YuNet runs on CPU and is outside the GPU workload queue.
- RF-DETR runs only during controlled shadow evaluation. It is disabled in
  face-control mode and removed after acceptance.
- Active voice does not need to pause or reduce YuNet.
- Explicit VLM requests retain their existing workload priority and consume the
  latest shared frame rather than opening a new camera poller.
- Only one rotated JPEG variant is produced for both detectors.

## Failure Handling

- If YuNet fails to load, tracking reports unavailable, holds no stale target,
  and returns to neutral without body searching.
- Detector timeouts contain the detector name, exception class, stage, frame
  ID, queue time, and inference time.
- Stale results are logged and ignored.
- Invalid landmark geometry is treated as a missed face, not as a controller
  fault.
- Reconnection never replays a gaze or body command derived from an expired
  frame.

## Public Status and Observability

Extend `/tracking/status` with:

- `target_source`: `face` or `none`
- `face_box`, normalized landmark coordinates, and face confidence
- face target age and estimator confidence
- YuNet cadence, queue latency, and inference latency
- trial mode and shadow-comparator health while shadow mode is enabled
- counts for face acquisitions, face losses, head commands, pivots, stale
  results, and invalid landmarks

At 1 Hz, `tracking.sample` records normalized face geometry, association
result, desired/actual head position, and detector timing. Routine image bytes
are never journaled.

## Shadow Evaluation

Before YuNet can control actuators, run it in shadow mode alongside the current
tracker on 300 to 500 real Robit frames. Include:

- frontal, profile, looking down, and briefly occluded faces
- near, typical-room, and far distances
- seated and standing positions
- bright, dim, and backlit scenes
- a second person entering and crossing the frame
- empty-room and face-like-object negative scenes
- frames immediately before and after head or body movement

YuNet and BlazeFace full-range may both be evaluated in the same harness. No
shadow detector result may issue an actuator command.

## Acceptance Criteria

YuNet becomes the primary detector only if the Robit-camera evaluation shows:

- at least 95% face retention after acquisition while a usable face remains
  visible
- reacquisition within two detector frames after a face returns
- fewer than 1% false-positive frames in the negative set and no persistent
  false target lasting two frames
- normalized eye-midpoint jitter below 0.03 p95 for a stationary person
- CPU inference latency below 20 ms p95 at the production frame size
- no GPU allocation by the face detector process
- no additional robot camera requests beyond the shared 2 FPS ceiling
- no more than four tracking head targets per second
- no body pivot while a stable face is centered
- no duplicate pivot caused by pre-pivot estimator state

The physical acceptance run must then retain a stationary face at least 95% of
the time for ten minutes and complete a thirty-minute voice-plus-tracking run
without camera, detector, or control-channel failure.

If YuNet misses the thresholds but BlazeFace passes them, BlazeFace becomes the
primary face detector without changing the controller contract. If neither
passes, roll back to RF-DETR and collect failure-specific frames before
considering fine-tuning.

## Rollout and Rollback

Introduce a configuration-selectable detector mode:

- `shadow`: current RF-DETR control with YuNet measurement only
- `face_only`: YuNet control with calm hold-and-neutral loss behavior
- `person_only`: previous RF-DETR behavior for rollback

Rollout proceeds from shadow evaluation to an attended ten-minute physical
test, then the thirty-minute mixed workload test. A configuration rollback must
not require firmware changes during the trial.

After YuNet passes acceptance:

- remove `person_only` and the RF-DETR sidecar from normal startup
- remove RF-DETR, PyTorch, Transformers, and detector-specific CUDA
  dependencies from `pc_tracking`
- rename the remaining sidecar and status text from RF-DETR tracking to face
  tracking
- retain the last accepted RF-DETR release in version control as the rollback
  boundary instead of carrying its runtime dependencies indefinitely

The trial temporarily adds `opencv-python-headless` and the YuNet ONNX model.
The accepted end state replaces the RF-DETR dependency stack rather than
adding another permanent detector stack.

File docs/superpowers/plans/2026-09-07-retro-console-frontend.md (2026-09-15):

# Restore Full Robit Console Functionality Plan

> **For agentic workers:** REQUIRED SUB-SKILL: Use superpowers:subagent-driven-development (recommended) or superpowers:executing-plans to implement this plan task-by-task.

**Goal:** Integrate camera, tracking, voice, chat, telemetry, memory, diagnostics, and manual robot controls into the approved RB-01 retro-anime HUD.

**Architecture:** Keep `web_control/index.html` as a dependency-free single-file client served by FastAPI. Six in-page subsystem screens share one browser state model and the existing HTTP/WebSocket interfaces; no backend schemas change.

**Tech Stack:** HTML5, CSS, browser JavaScript, FastAPI, pytest.

**Spec:** User-approved restore plan from 2026-09-07.

## Global Constraints

- Preserve the approved CRT console shell and visual grammar.
- Camera starts automatically; tracking requires explicit activation.
- Voice requires an explicit connect gesture and uses the brain WebSocket gateway.
- Manual control uses a simple session-local arm toggle and always stops on release/disarm.
- Browser-side voice tools and `/tracking/approach` remain absent.

---

### Task 1: Restore the browser contract

- [x] Add failing contract assertions for every required endpoint, frame matching, voice capture, control disarm, and six mode panels.
- [x] Confirm the approved static mock fails the operational contract.
- [x] Retain the visual identity assertions.

### Task 2: Build the six live subsystem screens

- [x] Preserve Overview and add separate Optical, Manual, Voice, Memory, and Diagnostic workspaces.
- [x] Make F1-F6 and the mode buttons switch exactly one workspace at a time.
- [x] Prevent decorative overlays from intercepting navigation.
- [x] Replace Overview's fictional subsystem indicators with live state summaries.

### Task 3: Restore camera, tracking, and perception

- [x] Restore low-rate camera capture, frame headers, object URL lifecycle, and visibility-aware polling.
- [x] Restore frame-matched normalized bounding boxes and tracking telemetry.
- [x] Keep tracking off until explicit start and expose explicit stop.
- [x] Restore perception summary and entities.

### Task 4: Restore control, chat, voice, memory, and diagnostics

- [x] Restore arm-gated drive and head commands with queued requests and automatic stop behavior.
- [x] Connect both emergency-stop controls to `/robot/stop` and disarm the UI.
- [x] Restore text chat and conversation rendering.
- [x] Restore realtime microphone capture, PCM16 streaming, transcript events, playback, and reconnect cleanup.
- [x] Restore read-only memory and action journal views.
- [x] Restore structured diagnostic refresh and reconnect controls.

### Task 5: Verify

- [x] Validate JavaScript syntax and static operational contracts.
- [x] Exercise all mode controls at the rendered desktop viewport with no horizontal overflow.
- [x] Verify camera, frame-matched overlay, tracking, chat, drive, release-stop, head, emergency stop, memory, and diagnostics against a mock brain.
- [ ] Run pytest after restoring the repository's broken Python 3.11 virtual environment.
- [ ] Run hardware-in-the-loop checks through `Scripts\run.bat` when Robit is available.

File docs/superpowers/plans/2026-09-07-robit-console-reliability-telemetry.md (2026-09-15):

# Robit Console Reliability and Telemetry Repair

## Goal

Repair the frontend as one cohesive monitoring-and-control console. Overview owns the sole live video and tracking overlay, F2 becomes Telemetry, every displayed value has a real source, LLM failures are observable, and X eyes appear only for a currently active critical robot-control fault.

## Global Constraints

- Preserve the retro visual language, six-key navigation, existing public control/chat routes, the 12-second ESP heartbeat watchdog, and compatibility with older firmware telemetry.
- Keep `/health.ok` as PC-process liveness, add truthful readiness/components, and never infer robot or LLM readiness from configuration alone.
- Poll browser telemetry once per second only while visible and retain 60 samples in memory; do not persist one-second telemetry.
- Report unsupported or missing measurements as `null`/`N/A`; never invent values or expose secrets.
- Execute no movement from malformed or unvalidated LLM output.
- Use tests first and preserve all unrelated user changes.

## Task 1: Fault lifecycle and canonical robot status

- Replace the persisted global safety latch with an active fault registry containing source, severity, message, and timestamp.
- Do not reactivate journaled transient faults at startup. Only critical actuation, ESP-watchdog, or confirmed robot-control faults force X eyes; LLM, voice, camera, and tracking failures are degraded services.
- Clear source-specific faults on recovery and send an immediate heartbeat/current desired state after reconnect.
- Normalize TCP, HTTP, and cached robot status into one non-blocking shape with source and age. Use online at <=3 seconds, stale at >3 through 15 seconds, offline after 15 seconds/disconnect, and fault for an active critical robot fault.
- Expose actual/requested eyes and the active override reason.
- Add red/green tests for restart, fault priority/recovery, noncritical degradation, transport normalization, freshness thresholds, and non-blocking cached status.

## Task 2: System telemetry and truthful readiness

- Add `GET /system/telemetry` with `host`, `llm`, `robot`, `tracking`, and active `faults` sections.
- Sample host CPU/RAM/process CPU and RSS, event-loop lag, network totals/rates, and optional NVIDIA GPU utilization/VRAM using a bounded `nvidia-smi` call.
- Explicitly pin psutil. Unsupported GPU collection returns structured unavailable data without failing the endpoint.
- Keep `/health.ok` as liveness and add `ready` plus per-component status, reason, latency, and check time.
- Probe LLM `/v1/models` on startup and every 10 seconds without token generation; track last inference latency/result.
- Add red/green tests for sampler deltas, counter reset, unavailable GPU, telemetry shape, readiness truth, and stale component state.

## Task 3: Reliable LLM action output

- Use the existing action Pydantic model as strict JSON Schema for `/chat/action`, matching the working vision pattern.
- Retry once without `response_format` only when a provider rejects that capability, while retaining identical Pydantic validation.
- Surface warm-up/probe failures rather than swallowing them and record request outcome/latency.
- Never execute invalid output.
- Add red/green tests for schema request, unsupported-schema fallback, valid action, malformed output, timeout, and recovery.

## Task 4: ESP32 telemetry extension

- Add bounded additive telemetry for uptime, Wi-Fi mode/RSSI, heap and minimum heap, total heap, PSRAM free/total, camera state, and heartbeat armed/fault flags.
- Preserve protocol size and old-client compatibility; do not change the watchdog safety behavior.
- Update PC normalization tests with both old and new packets. Hardware compile/flash and watchdog validation remain manual if no CLI is available.

## Task 5: Frontend rebuild

- Move the sole real camera and frame-matched tracking overlay into Overview with retry, tracking toggle, scene summary, and entities.
- Repurpose F2 Optical as Telemetry. Move overview-only wires/stamp/registration into the Overview panel.
- Replace hard-coded 73% with real GPU VRAM percentage or N/A. Replace the static plot with a rolling 60-second RX/TX graph and add robot RTT history on Telemetry.
- Present PC/LLM metrics separately from ESP metrics, including explicit loading/unknown/stale/offline/fault labels.
- Poll `/system/telemetry` at 1 Hz while visible, immediately refresh on visibility regain, and cap histories at 60 samples.
- Add chat pending/elapsed/error/retry behavior, disable duplicate sends, and guarantee WebSocket errors leave Connecting state.
- Add red/green frontend contract tests and verify extracted JavaScript with Node plus browser interactions across all tabs.

## Task 6: Integrated verification

- Run all Python suites, frontend syntax/contract tests, endpoint smoke checks, and browser checks.
- Verify exact acceptance requirements against the approved plan.
- Record unavailable hardware-only checks explicitly; do not claim them complete without an ESP flash and controlled heartbeat test.

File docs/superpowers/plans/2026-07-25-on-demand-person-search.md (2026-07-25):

# On-Demand RF-DETR Person Search Implementation Plan

> **For agentic workers:** REQUIRED SUB-SKILL: Use superpowers:subagent-driven-development (recommended) or superpowers:executing-plans to implement this plan task-by-task. Steps use checkbox (`- [ ]`) syntax for tracking.

**Goal:** Remove YuNet and continuous tracking, replacing them with a ten-second RF-DETR-only command that turns right until the first person is visible.

**Architecture:** A compact `PersonSearchService` owns one explicit finite search operation and is idle otherwise. It positions the head once, alternates fresh RF-DETR checks with bounded right pivots, and terminates on the first person, timeout, cancellation, or fault. The tracking sidecar returns only RF-DETR person detections.

**Tech Stack:** Python 3.11, asyncio, FastAPI/Pydantic, HTTPX, RF-DETR, existing frame and actuator brokers, pytest/AnyIO.

## Global Constraints

- Search is explicit only; no idle/background detector loop remains.
- Search timeout is `10` seconds.
- Head-height pose is pan `90`, tilt `75`.
- Each miss authorizes one right pivot at speed `140` for `350` ms.
- Wait `500` ms after the bounded movement ends before capturing.
- The first RF-DETR person at or above configured confidence ends the search.
- Do not center, associate, estimate, predict, or follow a detected person.
- Manual head, drive, and stop cancel the active search.
- Stale results from a cancelled generation cannot issue actuator commands.
- Routine image bytes remain memory-only.
- Preserve the existing persistent ESP control channel and browser robot APIs.
- Stage only files named by the active task because the worktree contains prior reliability changes.

## File Structure

- `pc_tracking/app/main.py`: RF-DETR-only sidecar and person-only response schema.
- `pc_tracking/app/yunet.py`: delete.
- `pc_tracking/app/model_assets.py`: delete.
- `pc_tracking/requirements.txt`: remove OpenCV.
- `pc_tracking/tests/test_main.py`: RF-DETR-only API/backend tests.
- `pc_tracking/tests/test_yunet.py`: delete.
- `pc_tracking/tests/test_model_assets.py`: delete.
- `pc_brain/app/tracking.py`: replace temporal tracker with detector client and `PersonSearchService`.
- `pc_brain/app/config.py`: retain only search configuration.
- `pc_brain/app/main.py`: construct search service, route commands, cancel on manual actions, and expose search APIs/status.
- `pc_brain/tests/test_tracking.py`: focused person-search state, freshness, timeout, cancellation, and failure tests.
- `pc_brain/tests/test_tracking_temporal.py`: delete.
- `pc_brain/tests/test_config.py`: search defaults/validation and removed-mode regression.
- `pc_brain/tests/test_main_endpoints.py`: endpoint, deterministic text, and manual cancellation tests.
- `README.md`, `docs/architecture.md`, `pc_brain/README.md`, `pc_brain/.env.example`, `pc_tracking/README.md`: remove YuNet/continuous tracking documentation and describe the one-shot command.

---

### Task 1: RF-DETR-Only Tracking Sidecar

**Files:**
- Modify: `pc_tracking/app/main.py`
- Modify: `pc_tracking/requirements.txt`
- Modify: `pc_tracking/tests/test_main.py`
- Delete: `pc_tracking/app/yunet.py`
- Delete: `pc_tracking/app/model_assets.py`
- Delete: `pc_tracking/tests/test_yunet.py`
- Delete: `pc_tracking/tests/test_model_assets.py`

**Interfaces:**
- Produces: `RFDetrBackend.detect(jpeg: bytes, threshold: float) -> tuple[list[PersonDetection], float]`.
- Produces: `POST /detect` response with `frame_id`, `captured_at`, `model`, `backend`, `latency_ms`, `queue_ms`, `request_bytes`, and `people`.
- Removes: face fields, detector modes, YuNet model loading, and minimum-face-size header.

- [ ] **Step 1: Rewrite sidecar tests to require person-only behavior**

Add literal tests asserting:

```python
def test_health_is_rfdetr_only(monkeypatch):
    monkeypatch.setattr(main, "backend", FakeBackend())
    payload = TestClient(main.app).get("/health").json()
    assert payload["model"] == "Roboflow/rf-detr-nano"
    assert "face" not in payload
    assert "detector_mode" not in payload

def test_detect_returns_only_people(monkeypatch):
    monkeypatch.setattr(main, "backend", FakeBackend(
        people=[PersonDetection(confidence=0.8, bounding_box=(0.1, 0.1, 0.4, 0.9))]
    ))
    response = TestClient(main.app).post(
        "/detect",
        content=b"jpeg",
        headers={
            "X-Robit-Frame-Id": "frame-1",
            "X-Robit-Captured-At": "2026-07-25T00:00:00Z",
            "X-Robit-Threshold": "0.4",
        },
    )
    assert response.status_code == 200
    assert len(response.json()["people"]) == 1
    assert "faces" not in response.json()
```

Also retain device selection, unavailable backend, serialized inference, empty-body, normalized-box, and frame metadata tests.

- [ ] **Step 2: Run the sidecar tests to verify RED**

Run in PowerShell:

```powershell
cd C:\Users\z1sou\HouseGremlin
.\pc_tracking\.venv\Scripts\python.exe -m pytest pc_tracking\tests\test_main.py -q
```

Expected: failures because health and detection responses still expose YuNet/mode fields.

- [ ] **Step 3: Collapse `pc_tracking/app/main.py` to RF-DETR only**

Delete `TrackingBackend`, `DetectionBatch`, `DetectorMode`, face imports, and face constants. Instantiate:

```python
backend = RFDetrBackend()
```

Define the response as:

```python
class DetectionResponse(BaseModel):
    frame_id: str
    captured_at: str
    model: str = MODEL_NAME
    backend: str
    latency_ms: float
    queue_ms: float = 0.0
    request_bytes: int = 0
    people: list[PersonDetection] = Field(default_factory=list)
```

Run `backend.detect(jpeg, x_robit_threshold)` in `asyncio.to_thread`, preserve the inference lock and metrics, and expose only RF-DETR status from `/health`.

- [ ] **Step 4: Delete YuNet code/tests and remove OpenCV**

Delete the four YuNet/model-asset files listed above. Remove:

```text
opencv-python-headless==4.12.0.88
```

from `pc_tracking/requirements.txt`.

- [ ] **Step 5: Verify the sidecar**

```powershell
cd C:\Users\z1sou\HouseGremlin
.\pc_tracking\.venv\Scripts\python.exe -m compileall -q pc_tracking\app pc_tracking\tests
.\pc_tracking\.venv\Scripts\python.exe -m pytest pc_tracking\tests -q
```

Expected: compile exits zero and all remaining sidecar tests pass.

### Task 2: Bounded Person Search Service

**Files:**
- Replace: `pc_brain/app/tracking.py`
- Replace: `pc_brain/tests/test_tracking.py`
- Delete: `pc_brain/tests/test_tracking_temporal.py`

**Interfaces:**
- Produces: `PersonCandidate`, `DetectorResult`, and `RFDetrClient`.
- Produces: `PersonSearchStatus`.
- Produces: `PersonSearchService.search()`, `cancel(reason)`, `cancel_now(reason)`, `status()`, `motion_authorized(generation, body)`, `start()`, and `shutdown()`.
- Consumes: `FrameBroker.get_rotated_jpeg(degrees, force_fresh=True)`.
- Consumes callbacks:
  `head_command(pan, tilt, generation)`,
  `move_command(direction, speed, duration_ms, generation)`, and
  `stop_command(generation)`.

- [ ] **Step 1: Write the bounded-search tests**

Use a fake clock/frame broker/detector and command recorders. Cover these exact sequences:

```python
await service.search()
assert commands[:2] == [("head", 90, 75), ("stop",)]
assert detector.frames == ["fresh-after-head"]
assert service.status().state == "found"
```

For an initial miss then detection:

```python
assert commands == [
    ("head", 90, 75),
    ("move", "right", 140, 350),
    ("stop",),
]
assert detector.frames == ["after-head", "after-settling"]
```

Also assert edge-of-frame detection produces no head/body correction, timeout is bounded, cancellation invalidates a delayed detector result, duplicate callers share one search, manual cancellation stops future commands, idle performs no detection, and detector/camera/actuator errors yield `faulted` with stage and exception class.

- [ ] **Step 2: Run focused tests to verify RED**

```powershell
cd C:\Users\z1sou\HouseGremlin
.\pc_brain\.venv\Scripts\python.exe -m pytest pc_brain\tests\test_tracking.py -q
```

Expected: imports and behavior fail because `PersonSearchService` does not exist.

- [ ] **Step 3: Replace temporal types with compact person-only models**

Keep normalized person box validation and detector frame/capture identity checks:

```python
class PersonCandidate(BaseModel):
    confidence: float = Field(ge=0.0, le=1.0)
    bounding_box: tuple[float, float, float, float]

class DetectorResult(BaseModel):
    frame_id: str
    captured_at: datetime
    model: str
    backend: str
    latency_ms: float
    queue_ms: float = 0.0
    people: list[PersonCandidate] = Field(default_factory=list)
```

`RFDetrClient.detect` sends only frame ID, capture time, and person threshold headers.

- [ ] **Step 4: Implement `PersonSearchService`**

Use states `idle`, `positioning`, `detecting`, `turning`, `found`, `timed_out`, `cancelled`, and `faulted`. `search()` creates or joins one task. `_run_search(generation)`:

```python
deadline = monotonic() + self.timeout_seconds
await self._authorized_head(90, 75, generation)
while self._authorized(generation):
    if monotonic() >= deadline:
        return await self._finish("timed_out", generation)
    frame, content = await self.broker.get_rotated_jpeg(
        self.rotate_degrees,
        force_fresh=True,
    )
    result = await self.detector.detect(frame, content, self.confidence)
    if result.people:
        self.last_detection_confidence = result.people[0].confidence
        return await self._finish("found", generation)
    await self._authorized_move("right", 140, 350, generation)
    await asyncio.sleep(0.35 + self.settling_seconds)
```

Before and after every await, verify the generation remains active. `_finish` sends ordinary stop before recording success/timeout. Cancellation increments generation, cancels the task, and prevents stale completion.

- [ ] **Step 5: Verify the service**

```powershell
cd C:\Users\z1sou\HouseGremlin
.\pc_brain\.venv\Scripts\python.exe -m pytest pc_brain\tests\test_tracking.py -q
```

Expected: all bounded-search tests pass.

### Task 3: Commands, Configuration, and Manual Cancellation

**Files:**
- Modify: `pc_brain/app/config.py`
- Modify: `pc_brain/app/main.py`
- Modify: `pc_brain/tests/test_config.py`
- Modify: `pc_brain/tests/test_main_endpoints.py`

**Interfaces:**
- Consumes Task 2 `PersonSearchService`.
- Produces: `POST /tracking/look-at-me`, `GET /tracking/status`, and cancellation-only `POST /tracking/stop`.
- Produces deterministic text/voice commands `look at me` and `find me`.

- [ ] **Step 1: Write failing configuration and endpoint tests**

Assert exact defaults:

```python
assert settings.tracking_search_timeout_seconds == 10.0
assert settings.tracking_head_height_pan == 90
assert settings.tracking_head_height_tilt == 75
assert settings.tracking_search_pivot_speed == 140
assert settings.tracking_search_pivot_duration_ms == 350
assert settings.tracking_search_settling_seconds == 0.5
```

Endpoint tests require `/tracking/start` to return `404`, `/tracking/look-at-me` to await `search()`, `/tracking/stop` to call `cancel("API request")`, and manual drive/head/stop to call `cancel_now` before actuator execution. Text tests require “look at me” and “find me” to return deterministic found/timeout/failure wording.

- [ ] **Step 2: Run tests to verify RED**

```powershell
cd C:\Users\z1sou\HouseGremlin
.\pc_brain\.venv\Scripts\python.exe -m pytest pc_brain\tests\test_config.py pc_brain\tests\test_main_endpoints.py -q
```

Expected: failures because old continuous settings/routes remain.

- [ ] **Step 3: Prune configuration and wire the service**

Remove detector mode, face, angular, cadence, association, and continuous pivot settings. Add validated search settings using existing integer/float helpers. Construct `PersonSearchService` with the exact global defaults and a stop callback that routes through `ActuatorBroker.stop()`.

Change tracking head publication to `wait_for_ack=True`. Use generation authorization for head, move, and stop callbacks.

- [ ] **Step 4: Replace deterministic commands and APIs**

Use:

```python
PERSON_SEARCH_MARKERS = re.compile(r"\b(?:look at me|find me)\b", re.IGNORECASE)
PERSON_SEARCH_CANCEL_MARKERS = re.compile(
    r"\b(?:stop looking|stop searching|cancel (?:the )?search)\b",
    re.IGNORECASE,
)
```

Remove continuous start/enable routing and its capability advertisement. Map terminal results to:

- found: `I found you.`
- timed out: `I couldn't find anyone.`
- cancelled: `I stopped looking.`
- faulted: `I couldn't look for you: <error>.`

- [ ] **Step 5: Verify configuration and endpoints**

```powershell
cd C:\Users\z1sou\HouseGremlin
.\pc_brain\.venv\Scripts\python.exe -m pytest pc_brain\tests\test_config.py pc_brain\tests\test_main_endpoints.py -q
```

Expected: all selected tests pass.

### Task 4: Remove Stale Surface and Verify the Hard Cleanup

**Files:**
- Modify: `README.md`
- Modify: `docs/architecture.md`
- Modify: `pc_brain/README.md`
- Modify: `pc_brain/.env.example`
- Modify: `pc_tracking/README.md`
- Test: `pc_brain/tests`
- Test: `pc_tracking/tests`

**Interfaces:**
- Documents PowerShell startup, explicit search, status, cancellation, and the person-only sidecar.

- [ ] **Step 1: Remove stale documentation and environment variables**

Document:

```powershell
cd C:\Users\z1sou\HouseGremlin
.\Scripts\run.bat
Invoke-RestMethod -Method Post http://localhost:8080/tracking/look-at-me
Invoke-RestMethod http://localhost:8080/tracking/status |
    ConvertTo-Json -Depth 6
```

Remove all YuNet, face-only, shadow, continuous following, angular calibration, and `/tracking/start` references. Add the six search defaults to `.env.example`.

- [ ] **Step 2: Prove deleted concepts are absent**

Run:

```powershell
cd C:\Users\z1sou\HouseGremlin
rg -n "YuNet|yunet|face_only|shadow|FaceCandidate|gaze_calculation|TRACKING_DETECTOR_MODE|tracking/start" `
  pc_brain pc_tracking README.md docs\architecture.md
```

Expected: no matches outside historical design/plan documents and virtual environments.

- [ ] **Step 3: Run fresh full verification**

```powershell
cd C:\Users\z1sou\HouseGremlin
.\pc_brain\.venv\Scripts\python.exe -m compileall -q pc_brain\app pc_brain\tests
.\pc_tracking\.venv\Scripts\python.exe -m compileall -q pc_tracking\app pc_tracking\tests
.\pc_brain\.venv\Scripts\python.exe -m pytest pc_brain\tests -q
.\pc_tracking\.venv\Scripts\python.exe -m pytest pc_tracking\tests -q
git diff --check
```

Expected: both compile commands exit zero, both full suites pass, and the whitespace check reports no errors.

- [ ] **Step 4: Run the attended PowerShell acceptance**

After stopping the existing supervisor with `Ctrl+C`:

```powershell
cd C:\Users\z1sou\HouseGremlin
.\Scripts\run.bat
```

Say “look at me” from outside the initial camera view. Confirm Robit sets the head-height pose, turns only right in bounded steps, stops at the first person detection, performs no centering correction, remains idle afterward, and times out within ten seconds when no person is present.

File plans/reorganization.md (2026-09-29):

# HouseGremlin Reorganization Plan (2026-09-18) — STATUS: Phases 1,2,3,5,6 DONE; Phase 4 PENDING

Goal: one coherent open-source-ready monorepo. Three hard package boundaries,
no god-files, every package runnable in isolation with zero hardware.

**Context rules for the working session(s):**
- This file is self-contained. Do NOT re-survey the repo; trust it until a step fails.
- One phase = one commit. Never start a phase without its test baseline green.
- Baselines (verified 2026-09-18, still valid after all commits): brain **227**,
  tracking **5**, memory **57** tests. Venvs: `brain/.venv`, `tracking/.venv`,
  `memory/.venv` (all gitignored). llama.cpp at `C:\Tools\llama.cpp`.
- Windows + Git Bash. `du` on the repo root TIMES OUT (5 GB+ of venvs) — never use it;
  use `git ls-files` / targeted `ls`.
- No LLM/VRAM needed for any phase. Robot may be off.

## DONE log (commits, all test-gated at 227/5/57)
- **Phase 1** `1860b3d` — swept junk: .superpowers untracked+gitignored, cuda_paths.py,
  one-shot patch script, YuNet plan (user confirmed delete), spike WAVs, orphan Scripts.
- **Phase 2** `485ad4a` — README Naming section: HouseGremlin = repo/brand,
  Robit = robot. Code already consistently ROBIT_*; no rename needed.
- **Phase 3** `e5a251f` — git mv pc_brain→brain, pc_tracking→tracking, pc_memory→memory
  (87 files, history preserved) + all reference rewrites (42 files: imports, scripts,
  bats, supervisor, pytest/pyright/pyproject, .gitignore, docs).
- **Phase 5** `5f53d1a` — tracking/.env.example + memory/.env.example added; keep-in-sync
  headers on both sanitization.py copies (decision: keep per-service, NOT shared pkg).
- **Phase 6** `f7eb8fe` — README layout table + port map + ASCII diagram; architecture.md
  gains Memory Service section; stale "thin scaffold" copy replaced.

## Phase 4 — Split the god-file (PENDING — its own session, highest risk)
`brain/app/main.py` is 1,693 lines / 80 defs. Extract in this order, tests after EACH:
1. `robot_client.py`: robot_request/robot_get/robot_post/heartbeat/cached_robot_status/
   fetch_robot_camera_frame/camera_urls (~lines 555–735). Pure move + re-export from main
   so imports don't churn.
2. `actions.py`: validate_action_payload/sanitized_action_payload/normalize_llm_action_body/
   execute_robot_action/execute_action_payload/require_model_eye_expression.
3. Shrink main.py to routes + lifespan + DI getters (target < 500 lines).
Keep module-level singletons (`realtime_gateway` etc.) where they are; move only if a step
forces it. Gate after each: 227 green + `import brain.app.main` smoke.

## Phase 5 — Dedup + package hygiene (1 commit)
- `sanitization.py` is byte-identical in brain/ and tracking/. **Decision: keep one copy per
  service** (verified 2026-09-18): brain has 3 consumers (coordinator, main, tracking) so
  inlining would duplicate it 3x; a shared package for 46 lines is over-engineering.
  Add a one-line header comment on each: "Keep in sync with <other>/app/sanitization.py".
- Each package: own README ("run me alone in 5 min"), `.env.example` generated from
  config defaults, pyproject.toml.

## Phase 6 — Docs pass (1 commit)
- Root README: rewrite intro = what talks to what + diagram (ASCII fine), per-package
  run instructions, contributor on-ramp ordered by barrier: memory (no deps) →
  tracking (GPU) → brain (robot+LLM+camera).
- `docs/architecture.md`: rewrite — predates memory/ingestion/researcher.
- Keep plans/ as historical; mark superseded ones.

## Out of scope (separate conversations)
- realtime_gateway.py internals (880 lines, self-contained — split only if asked)
- Any behavior changes, new features, telemetry→memory wiring
- Moving memory to its own repo (revisit once brain/tracking stabilize)

## Session budget
Phase 1+2: one short session. Phase 3: one session (mechanical but wide).
Phase 4: its own session(s), slowest. Phases 5+6: one session.
If a phase stalls >2 attempts, STOP and report — don't improvise structure.

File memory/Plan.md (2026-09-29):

# Plan: memory — knowledge graph memory with routed retrieval

## Context

Robit needs durable semantic memory that autonomous agents can grow over time. The user
wants `memory/` (currently empty) to be a **knowledge graph** where agents slowly add
facts derived from scouring the internet or asking the owner questions — e.g.
"sky is blue" → *because* → "Rayleigh scattering by molecules in the atmosphere".

Retrieval goal: given a question, find an **entrance node**, then use a **routing model**
to scour the graph for the nodes most likely to answer it; all discovered nodes are added
to context. Endgame is a learned routing model; we start with LLM-as-router and log every
retrieval trace as its training data.

This intentionally pivots DESIGN.md's "RAG before GraphRAG" guidance for this component —
graph-shaped data + LLM routing is the point here. `DESIGN.md` will be updated so the two
don't contradict (memory becomes the substrate Gate 4 semantic memory builds on).

### Does it make sense?

Yes — with three caveats the design must handle:

1. **Extraction quality is the bottleneck.** Garbage triples → garbage graph. Every fact
   carries provenance; equivalent facts merge; contradictions are flagged, not silently
   overwritten.
2. **LLM routing is slow and token-hungry on a local 4B model.** Budget hops (≤3) and
   candidate beam (≤6), early-stop when the router says "enough". Ingestion stays
   background/slow; retrieval must stay bounded (~seconds, not minutes).
3. **Entrance finding still needs hybrid search** (FTS5 + vectors). The router improves on
   a good seed set; it doesn't replace lexical/semantic entry points.

## Approach

### Graph model

One graph, two node kinds, typed edges:
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

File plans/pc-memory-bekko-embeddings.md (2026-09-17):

# pc_memory — Bekko Embedding Integration Plan

Status: **Phases 1–4 DONE (2026-09-15)**. Phase 4b (telemetry ingestion driver) + Phase 4c (autonomous web researcher) DONE (2026-09-17). Phases 5, 6.1/6.2/6.4 pending.

## Model choice

**`hotchpotch/bekko-embedding-v1-a25m-GGUF` → `bekko-embedding-v1-a25m-Q8_0.gguf` (137 MB)**
- 24.9M params, 384-dim output, mean pooling + L2 normalize, 8k context.
- ~57.5 MMTEB retrieval score — beats BGE-M3 with ~12x fewer params; a25 is the
  right size (a8m saves nothing meaningful at this scale, Q8_0 keeps accuracy near F16).
- Served via llama-server `--embedding --pooling mean --embd-normalize 2` on **127.0.0.1:8093**.
- Model file: `C:\dev\HouseGremlin\models\bekko-embedding-v1-a25m-Q8_0.gguf` (gitignored).
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

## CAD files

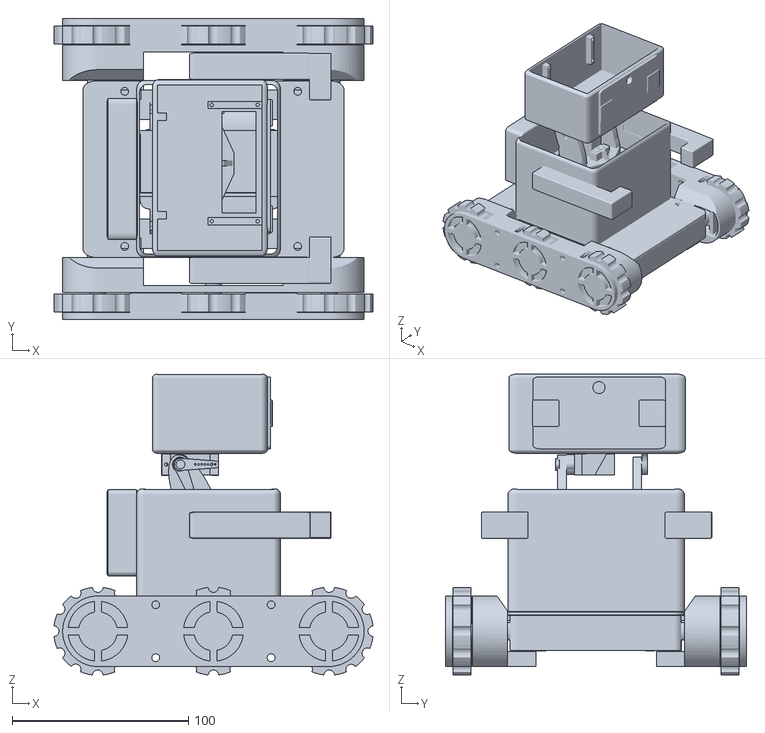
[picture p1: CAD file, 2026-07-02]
Maindesign.stl
180.8 x 170.6 x 170.6

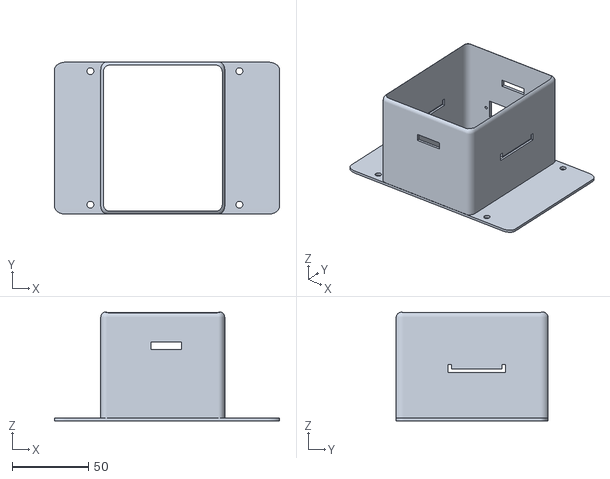
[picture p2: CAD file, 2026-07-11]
cad/Robit(47).stl
148.0 x 100.2 x 71.7

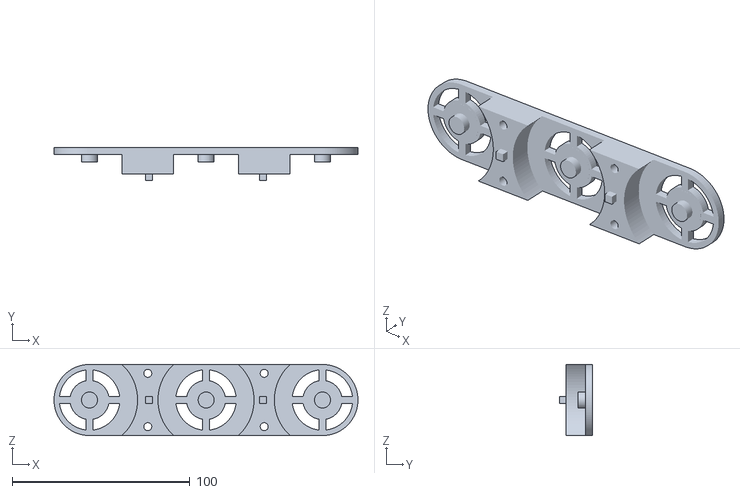
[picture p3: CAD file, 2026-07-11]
cad/Robit(55).stl
170.9 x 18.5 x 40.0

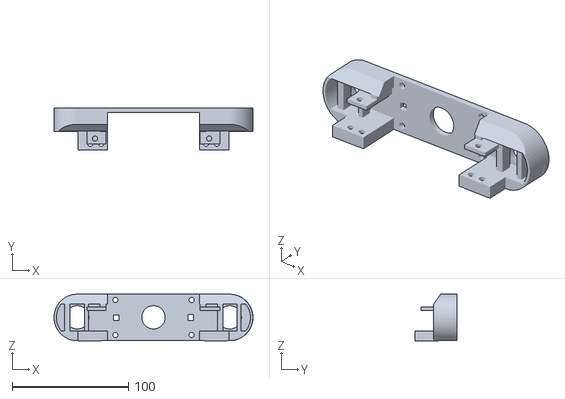
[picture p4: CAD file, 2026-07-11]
cad/Robit(52).stl
170.9 x 36.0 x 40.1

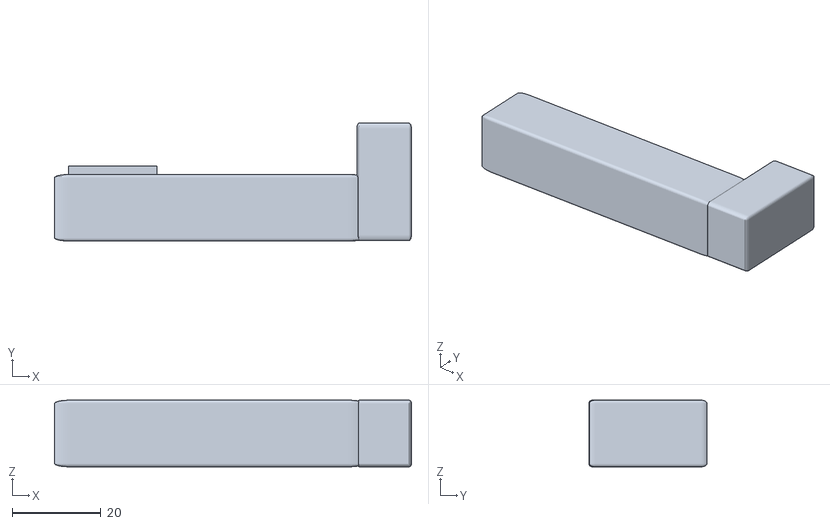
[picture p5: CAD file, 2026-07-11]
cad/Robit(48).stl
80.3 x 26.6 x 15.0

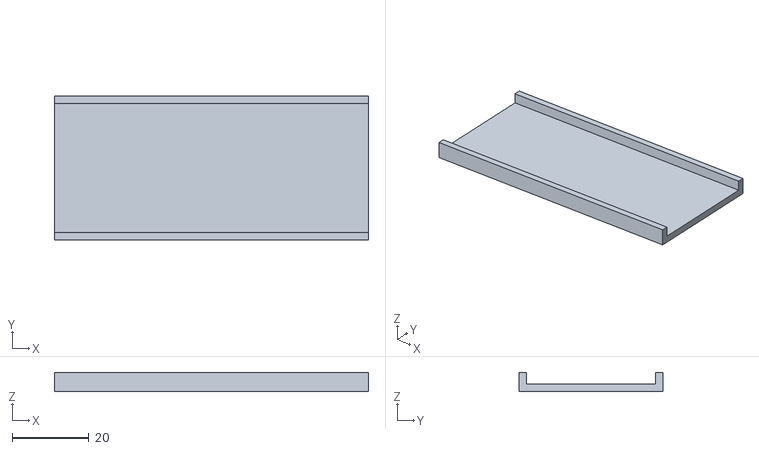
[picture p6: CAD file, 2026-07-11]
cad/Robit(46).stl
81.6 x 37.5 x 5.00

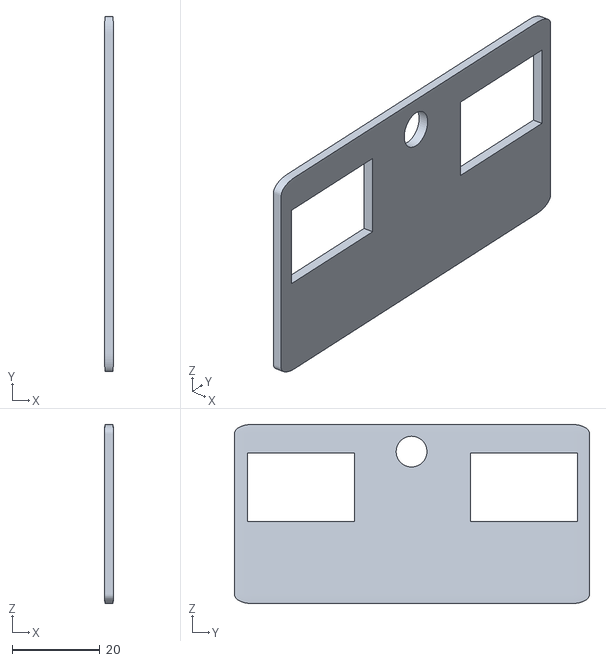
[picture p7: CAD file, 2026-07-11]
cad/Robit(41).stl
2.00 x 80.8 x 40.8

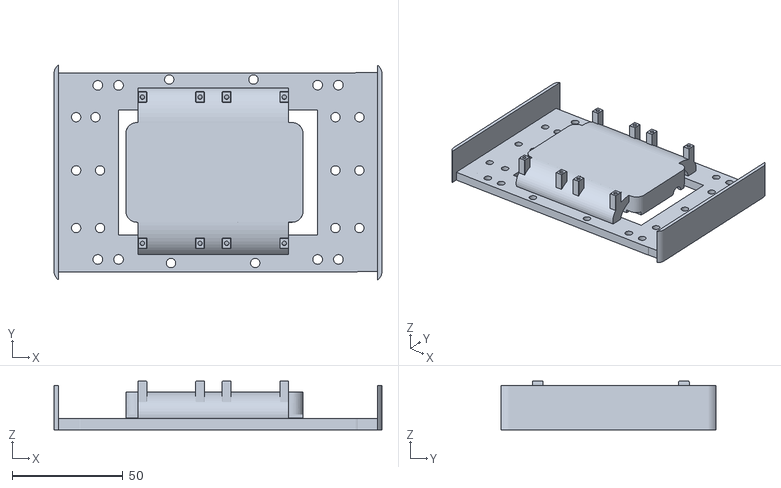
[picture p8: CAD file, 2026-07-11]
cad/Robit(50).stl
148.0 x 97.1 x 22.1

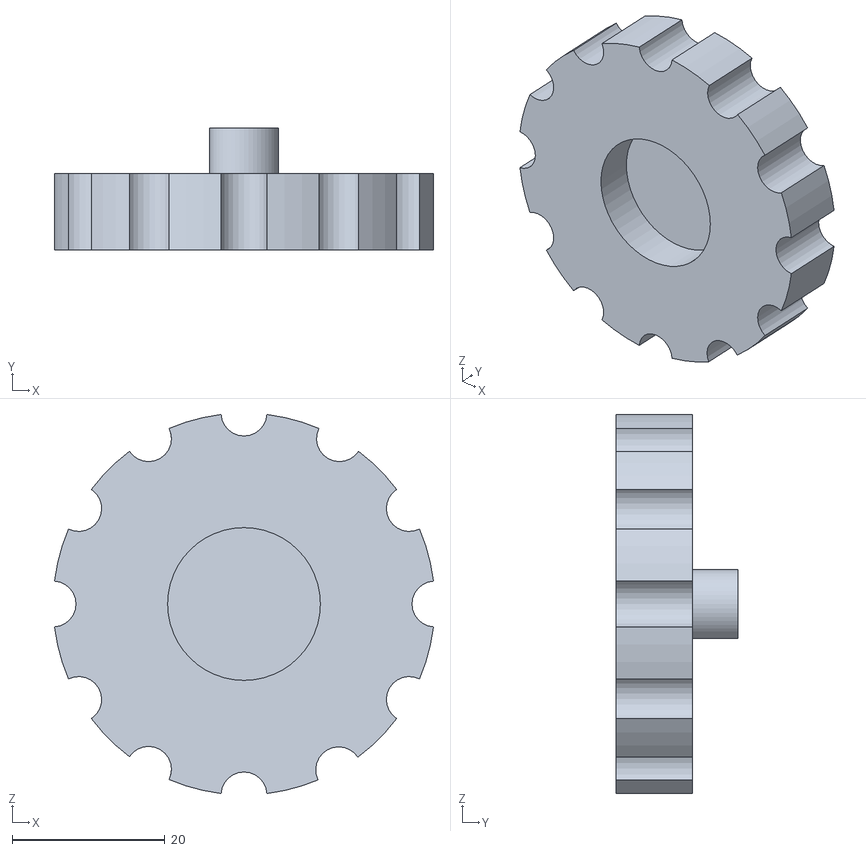
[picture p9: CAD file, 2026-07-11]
cad/Robit(53).stl
49.6 x 15.9 x 49.6

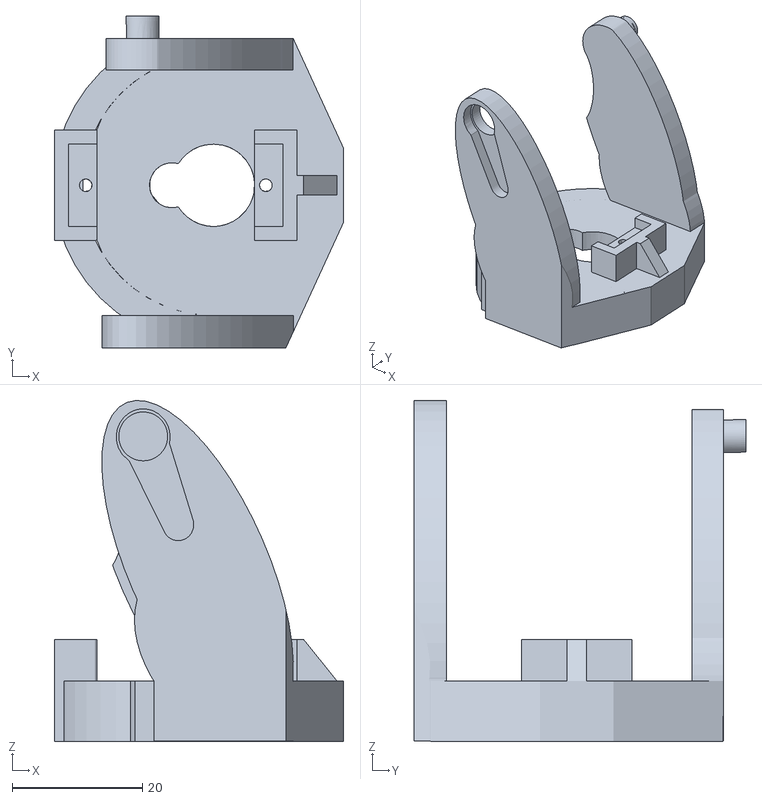
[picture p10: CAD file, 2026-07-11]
cad/Robit(44).stl
44.4 x 51.0 x 52.4

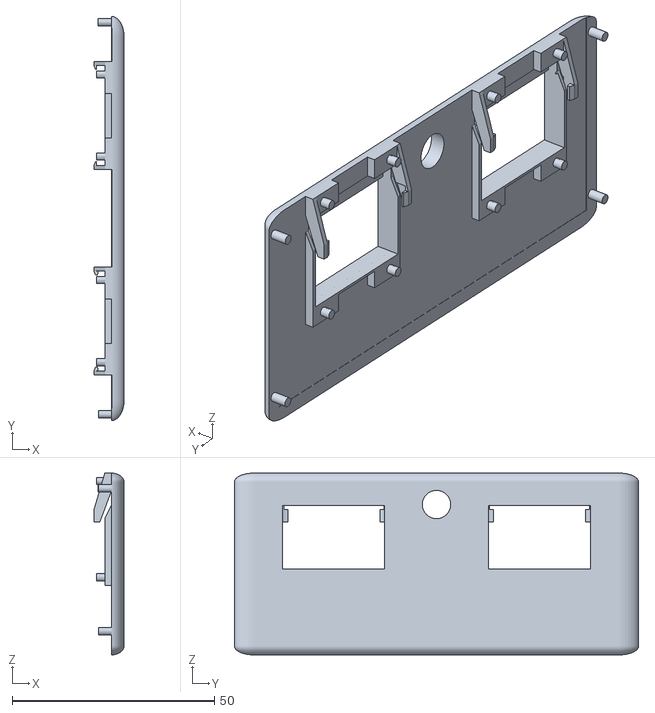
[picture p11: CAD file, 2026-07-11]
cad/Robit(42).stl
7.46 x 100.0 x 45.0

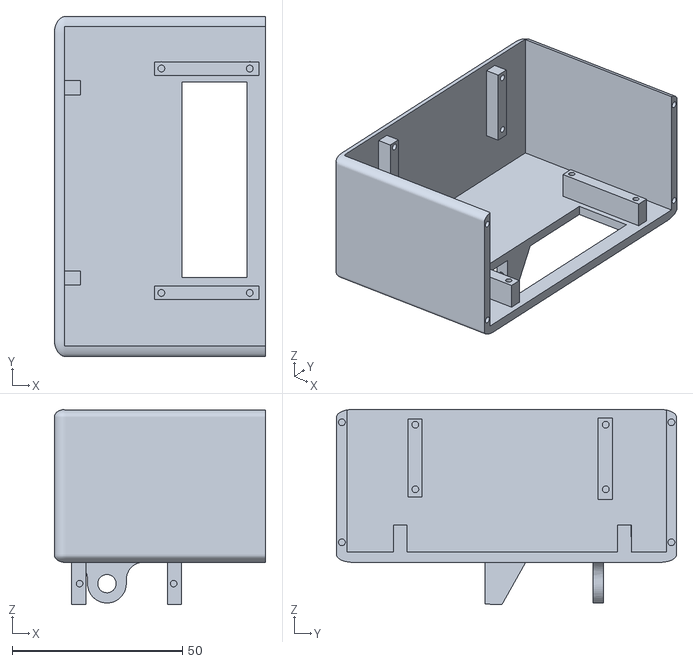
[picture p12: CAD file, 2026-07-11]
cad/Robit(43).stl
62.2 x 100.0 x 57.4

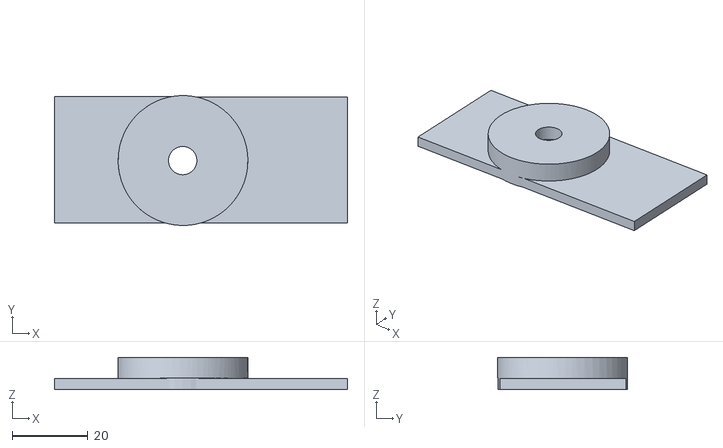
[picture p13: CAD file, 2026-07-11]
cad/Robit(45).stl
77.6 x 34.4 x 8.60

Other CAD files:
cad/Robit(49).stl
cad/Robit(51).stl
cad/Robit(54).stl

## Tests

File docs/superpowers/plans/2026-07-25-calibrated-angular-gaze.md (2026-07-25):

# Calibrated Angular Gaze Implementation Plan

> **For implementation:** REQUIRED SUB-SKILL: Use superpowers:executing-plans
> task-by-task. Use delegated execution only when the user explicitly requests
> subagents. Steps use checkbox (`- [ ]`) syntax for tracking.

**Goal:** Center a freshly acquired face with one calculated absolute head
target, followed by at most one residual correction, while firmware preserves
fluid acceleration-limited motion.

**Architecture:** Add a pure pinhole-camera angle helper and validated
calibration settings to the existing tracker. Extend the persistent control
channel with telemetry receive age, then make face-only gaze originate from
fresh actual servo telemetry or the last acknowledged fallback position.
Existing association, broker coalescing, pivot settling, and loss behavior
remain unchanged.

**Tech Stack:** Python 3.11, asyncio, FastAPI/Pydantic, existing NDJSON control
channel, pytest/AnyIO.

## Global Constraints

- Horizontal FOV defaults to `62.0` degrees and vertical FOV to `48.5`.
- Pan and tilt angle gains default to `1.0`.
- Angular deadband defaults to `2.0` degrees.
- Telemetry is fresh only while connected and no more than one second old.
- Final targets remain clamped to pan `55..135` and tilt `35..115`.
- Initial face acquisition uses fresh eye geometry, not a smoothed center.
- No gaze update is allowed during pivot settling.
- Tracking publication remains capped by the actuator broker at 4 Hz.
- No image bytes are logged or journaled.
- Stage only files listed by each task; preserve the dirty reliability work.

## File Structure

- `pc_brain/app/config.py`: validated camera and servo calibration settings.
- `pc_brain/app/control_channel.py`: telemetry receive time and age-aware head
  state.
- `pc_brain/app/tracking.py`: pure angle calculation, absolute target
  calculation, controller integration, and diagnostics.
- `pc_brain/app/main.py`: passes settings and the age-aware telemetry provider.
- `pc_brain/tests/test_config.py`: invalid/default calibration tests.
- `pc_brain/tests/test_control_channel.py`: hello/telemetry age tests.
- `pc_brain/tests/test_tracking.py`: geometry, origin, clamping, deadband, and
  initial-command tests.
- `pc_brain/tests/test_tracking_temporal.py`: residual and settling regression.
- `pc_brain/.env.example`, `pc_brain/README.md`: calibration documentation.

---

### Task 1: Pure Camera Geometry and Validated Calibration

**Files:**
- Modify: `pc_brain/app/config.py`
- Modify: `pc_brain/app/tracking.py`
- Modify: `pc_brain/tests/test_config.py`
- Modify: `pc_brain/tests/test_tracking.py`

**Interfaces:**
- Produces:
  `camera_angle_degrees(image_error: float, fov_degrees: float) -> float`.
- Produces settings `tracking_camera_horizontal_fov_degrees`,
  `tracking_camera_vertical_fov_degrees`, `tracking_pan_angle_gain`,
  `tracking_tilt_angle_gain`, and `tracking_angular_deadband_degrees`.

- [ ] **Step 1: Write failing geometry and configuration tests**

```python
def test_pinhole_camera_angle_matches_edge_geometry():
    assert camera_angle_degrees(0.40, 62.0) == pytest.approx(25.68, abs=0.05)
    assert camera_angle_degrees(-0.40, 62.0) == pytest.approx(-25.68, abs=0.05)
    assert camera_angle_degrees(0.0, 62.0) == 0.0

def test_angular_tracking_defaults(monkeypatch, tmp_path):
    monkeypatch.setenv("ROBIT_DATA_DIR", str(tmp_path))
    for name in (
        "ROBIT_TRACKING_CAMERA_HORIZONTAL_FOV_DEGREES",
        "ROBIT_TRACKING_CAMERA_VERTICAL_FOV_DEGREES",
        "ROBIT_TRACKING_PAN_ANGLE_GAIN",
        "ROBIT_TRACKING_TILT_ANGLE_GAIN",
        "ROBIT_TRACKING_ANGULAR_DEADBAND_DEGREES",
    ):
        monkeypatch.delenv(name, raising=False)
    settings = load_settings()
    assert settings.tracking_camera_horizontal_fov_degrees == 62.0
    assert settings.tracking_camera_vertical_fov_degrees == 48.5
    assert settings.tracking_pan_angle_gain == 1.0
    assert settings.tracking_tilt_angle_gain == 1.0
    assert settings.tracking_angular_deadband_degrees == 2.0
```

Parameterize invalid FOV values `0`, `180`, and `nan`; invalid gain values `0`,
`-1`, and `nan`; and invalid deadband values `-1` and `nan`.

- [ ] **Step 2: Verify RED**

Run in PowerShell:

```powershell
cd C:\Users\z1sou\HouseGremlin
.\pc_brain\.venv\Scripts\python.exe -m pytest `
  pc_brain\tests\test_config.py `
  pc_brain\tests\test_tracking.py `
  -k "angular or pinhole" -q
```

Expected: imports/settings fail because the helper and settings do not exist.

- [ ] **Step 3: Implement the pure helper and settings validation**

```python
def camera_angle_degrees(image_error: float, fov_degrees: float) -> float:
    half_fov = radians(fov_degrees) / 2.0
    return degrees(atan(2.0 * image_error * tan(half_fov)))
```

Add a finite range validator in `config.py`:

```python
def _finite_float_env(
    name: str,
    default: float,
    *,
    minimum: float,
    maximum: float | None = None,
    minimum_inclusive: bool = True,
) -> float:
    value = _float_env(name, default)
    valid_minimum = value >= minimum if minimum_inclusive else value > minimum
    if (
        not math.isfinite(value)
        or not valid_minimum
        or (maximum is not None and value >= maximum)
    ):
        raise ValueError(f"{name} has an invalid value")
    return value
```

Use it for the five exact defaults in the global constraints.

- [ ] **Step 4: Verify GREEN**

```powershell
cd C:\Users\z1sou\HouseGremlin
.\pc_brain\.venv\Scripts\python.exe -m pytest `
  pc_brain\tests\test_config.py `
  pc_brain\tests\test_tracking.py `
  -k "angular or pinhole" -q
```

Expected: selected tests pass.

### Task 2: Fresh Actual Head Telemetry

**Files:**
- Modify: `pc_brain/app/control_channel.py`
- Modify: `pc_brain/app/main.py`
- Modify: `pc_brain/tests/test_control_channel.py`

**Interfaces:**
- Produces: `EspControlChannel.head_state() -> dict[str, Any]`.
- Returned metadata keys:
  `control_connected: bool`, `telemetry_age_seconds: float | None`,
  plus the latest telemetry fields.
- Consumes: `time.monotonic()`.

- [ ] **Step 1: Write failing telemetry freshness test**

```python
@pytest.mark.anyio
async def test_head_state_reports_connection_and_telemetry_age(monkeypatch):
    clock = [100.0]
    monkeypatch.setattr(control_channel.time, "monotonic", lambda: clock[0])
    channel = EspControlChannel("127.0.0.1")
    channel.telemetry = {"pan_actual": 91, "tilt_actual": 88}
    channel._telemetry_received_at = clock[0]
    channel._ready.set()

    assert channel.head_state()["control_connected"] is True
    assert channel.head_state()["telemetry_age_seconds"] == 0.0
    clock[0] += 1.2
    assert channel.head_state()["telemetry_age_seconds"] == pytest.approx(1.2)
```

Also assert both hello state and later telemetry update
`_telemetry_received_at`.

- [ ] **Step 2: Verify RED**

```powershell
cd C:\Users\z1sou\HouseGremlin
.\pc_brain\.venv\Scripts\python.exe -m pytest `
  pc_brain\tests\test_control_channel.py `
  -k "head_state or telemetry_age" -q
```

Expected: `head_state` or `_telemetry_received_at` is missing.

- [ ] **Step 3: Implement age-aware state**

Initialize `_telemetry_received_at = 0.0`, update it whenever hello state or
`telemetry` is accepted, and add:

```python
def head_state(self) -> dict[str, Any]:
    received_at = self._telemetry_received_at
    return {
        **self.telemetry,
        "control_connected": self._ready.is_set(),
        "telemetry_age_seconds": (
            max(0.0, time.monotonic() - received_at)
            if received_at > 0.0
            else None
        ),
    }
```

Change `get_tracking_service` to provide
`control_channel.head_state()` when a channel exists.

- [ ] **Step 4: Verify GREEN**

```powershell
cd C:\Users\z1sou\HouseGremlin
.\pc_brain\.venv\Scripts\python.exe -m pytest `
  pc_brain\tests\test_control_channel.py -q
```

Expected: all control-channel tests pass.

### Task 3: Absolute Face Target and Diagnostics

**Files:**
- Modify: `pc_brain/app/tracking.py`
- Modify: `pc_brain/app/main.py`
- Modify: `pc_brain/tests/test_tracking.py`
- Modify: `pc_brain/tests/test_tracking_temporal.py`
- Modify: `pc_brain/tests/test_main_endpoints.py`

**Interfaces:**
- Produces:
  `HeadTargetCalculation(origin_pan, origin_tilt, target_pan, target_tilt,
  horizontal_error_degrees, vertical_error_degrees, origin_source)`.
- Produces:
  `calculate_face_head_target(...) -> HeadTargetCalculation`.
- Adds `gaze_calculation` to `TrackingStatus` and `tracking.sample`.
- Consumes Task 1 settings and Task 2 `head_state()`.

- [ ] **Step 1: Write failing absolute-target tests**

```python
def test_face_target_uses_fresh_actual_telemetry():
    result = calculate_face_head_target(
        eye_midpoint=(0.90, 0.50),
        telemetry={
            "control_connected": True,
            "telemetry_age_seconds": 0.2,
            "pan_actual": 80,
            "tilt_actual": 90,
        },
        fallback=(100, 85),
        horizontal_fov_degrees=62.0,
        vertical_fov_degrees=48.5,
        pan_gain=1.0,
        tilt_gain=1.0,
        pan_sign=1,
        tilt_sign=1,
    )
    assert result.origin_source == "actual"
    assert result.origin_pan == 80
    assert result.target_pan == 106

def test_face_target_falls_back_and_clamps():
    result = calculate_face_head_target(
        eye_midpoint=(1.0, 0.0),
        telemetry={"control_connected": False},
        fallback=(130, 40),
        horizontal_fov_degrees=62.0,
        vertical_fov_degrees=48.5,
        pan_gain=1.0,
        tilt_gain=1.0,
        pan_sign=1,
        tilt_sign=1,
    )
    assert result.origin_source == "acknowledged"
    assert (result.target_pan, result.target_tilt) == (135, 35)
```

Add async tests proving centered eyes emit no command and initial acquisition
at `x=0.90` emits one absolute target based on supplied actual telemetry rather
than the old 18-degree/smoothed step.

- [ ] **Step 2: Verify RED**

```powershell
cd C:\Users\z1sou\HouseGremlin
.\pc_brain\.venv\Scripts\python.exe -m pytest `
  pc_brain\tests\test_tracking.py `
  -k "face_target or angular_deadband or initial_angular" -q
```

Expected: calculation type/function and absolute behavior are absent.

- [ ] **Step 3: Implement calculation and face-only integration**

Create a frozen dataclass and pure function. Round final servo targets once,
after gains/signs, and clamp to existing ranges. Treat telemetry as actual only
when connected, age is numeric and `<= 1.0`, and actual pan/tilt are non-boolean
integers.

Pass all calibration settings into `PersonTrackingService`. In
`_update_head_and_body`, use the target's fresh `eye_midpoint` for a
`FaceObservation`; retain the existing person controller for shadow and
person-only modes. Emit no command when both calculated angular errors are
within the angular deadband.

Set `self._last_gaze_calculation` before command publication. Do not update
`self.head_pan` or `self.head_tilt` unless the command completes under the
existing generation check.

- [ ] **Step 4: Add residual, status, and pivot tests**

Add literal tests that:

- the next fresh face frame produces only the residual correction;
- an in-deadband residual emits no command;
- settling frames retain the previous calculation and estimator;
- `/tracking/status` returns `gaze_calculation`;
- `tracking.sample` includes calculation numbers and no image keys;
- a just-issued head target does not immediately authorize a body pivot.

- [ ] **Step 5: Verify GREEN**

```powershell
cd C:\Users\z1sou\HouseGremlin
.\pc_brain\.venv\Scripts\python.exe -m pytest `
  pc_brain\tests\test_tracking.py `
  pc_brain\tests\test_tracking_temporal.py `
  pc_brain\tests\test_main_endpoints.py -q
```

Expected: all selected tests pass.

### Task 4: Configuration Handoff, Documentation, and Full Verification

**Files:**
- Modify: `pc_brain/.env.example`
- Modify: `pc_brain/README.md`
- Test: `pc_brain/tests`
- Test: `pc_tracking/tests`

**Interfaces:**
- Documents the five calibration variables and PowerShell trial commands.
- Preserves all existing browser and tracking endpoints.

- [ ] **Step 1: Add exact environment defaults**

```dotenv
ROBIT_TRACKING_CAMERA_HORIZONTAL_FOV_DEGREES=62
ROBIT_TRACKING_CAMERA_VERTICAL_FOV_DEGREES=48.5
ROBIT_TRACKING_PAN_ANGLE_GAIN=1.0
ROBIT_TRACKING_TILT_ANGLE_GAIN=1.0
ROBIT_TRACKING_ANGULAR_DEADBAND_DEGREES=2
```

Document that gains above `1.0` increase correction and values below `1.0`
reduce it. Tell operators to change one axis at a time in `face_only`.

- [ ] **Step 2: Run fresh full verification**

```powershell
cd C:\Users\z1sou\HouseGremlin
.\pc_brain\.venv\Scripts\python.exe -m compileall -q pc_brain\app pc_brain\tests
.\pc_tracking\.venv\Scripts\python.exe -m compileall -q pc_tracking\app pc_tracking\tests
.\pc_brain\.venv\Scripts\python.exe -m pytest pc_brain\tests -q
.\pc_tracking\.venv\Scripts\python.exe -m pytest pc_tracking\tests -q
git diff --check
```

Expected: both compile commands exit zero, all tests pass, and the whitespace
check reports no errors.

- [ ] **Step 3: Run attended PowerShell trial**

After stopping the previous supervisor with `Ctrl+C`:

```powershell
cd C:\Users\z1sou\HouseGremlin
$env:ROBIT_TRACKING_DETECTOR_MODE = "face_only"
.\Scripts\run.bat
```

Verify the first post-acquisition movement centers the face with no more than
one residual correction and remains physically acceleration-limited. Inspect:

```powershell
Invoke-RestMethod http://localhost:8080/tracking/status |
    ConvertTo-Json -Depth 8
```

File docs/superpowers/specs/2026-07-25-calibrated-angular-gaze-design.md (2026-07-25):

# Calibrated Angular Gaze Controller Design

## Summary

Replace Robit's repeated fixed-gain head steps with one calculated absolute
head target derived from the detected eye midpoint, the camera field of view,
and the ESP's reported actual head position. The firmware continues to own
velocity- and acceleration-limited servo motion, so the PC can request the
correct destination immediately without making the physical movement abrupt.

This changes only face-gaze publication. YuNet detection, temporal face
association, manual leases, actuator coalescing, pivot settling, and calm
face-loss behavior remain intact.

## Root Cause

The current controller converts normalized image error into servo steps with:

```text
servo_step = image_error * 40
```

Each step is capped at 18 degrees. Stable face detections run at 1 FPS, so an
under-sized correction necessarily waits roughly another second for every
residual step. Temporal smoothing further reduces the early correction.

The camera already supplies enough geometry for a better estimate. For a
62-degree horizontal field of view, a face at normalized `x = 0.90` is about
25.7 camera degrees from center, while the current linear rule requests only
16 servo degrees.

## Angular Controller

For a fresh face detection, calculate:

```text
error_x = eye_midpoint_x - 0.5
error_y = eye_midpoint_y - 0.5

camera_angle_x = atan(2 * error_x * tan(horizontal_fov / 2))
camera_angle_y = atan(2 * error_y * tan(vertical_fov / 2))

pan_correction  = degrees(camera_angle_x) * pan_gain * pan_sign
tilt_correction = degrees(camera_angle_y) * tilt_gain * tilt_sign
```

The absolute command is based on actual telemetry:

```text
target_pan  = actual_pan  + pan_correction
target_tilt = actual_tilt + tilt_correction
```

The control channel records a monotonic receive timestamp whenever hello state
or telemetry arrives. Actual telemetry is fresh when the channel is connected,
`pan_actual` and `tilt_actual` are valid integers, and that timestamp is no more
than one second old. Otherwise, use the controller's last
acknowledged/synchronized head position. Never compound a new correction from
an unacknowledged desired target.

Clamp the final target to the existing servo ranges: pan `55..135`, tilt
`35..115`. Do not apply the old 18-degree incremental step cap. The maximum
camera correction is naturally bounded by half the configured field of view,
and the absolute servo clamp remains authoritative.

## Calibration and Defaults

Add these settings:

- `ROBIT_TRACKING_CAMERA_HORIZONTAL_FOV_DEGREES=62`
- `ROBIT_TRACKING_CAMERA_VERTICAL_FOV_DEGREES=48.5`
- `ROBIT_TRACKING_PAN_ANGLE_GAIN=1.0`
- `ROBIT_TRACKING_TILT_ANGLE_GAIN=1.0`
- `ROBIT_TRACKING_ANGULAR_DEADBAND_DEGREES=2.0`

The default vertical field of view is the 4:3 pinhole equivalent of the
existing 62-degree horizontal field of view. Gains permit physical calibration
without changing controller code. Signs continue to use the existing
`ROBIT_TRACKING_PAN_SIGN` and `ROBIT_TRACKING_TILT_SIGN`.

All field-of-view values must be finite and between 1 and 179 degrees. Gains
must be finite and greater than zero. The angular deadband must be finite and
non-negative.

## Temporal Behavior and Fluidity

The first command after the required two-frame face acquisition uses the fresh
eye midpoint directly rather than the lagging smoothed center. Later frames
calculate a residual angular correction. Prediction remains capped at 0.5
seconds, but prediction cannot make an initial correction larger than the
fresh geometric correction.

No command is emitted when both angular errors are within the configured
two-degree deadband. Tracking publication remains capped at 4 Hz by the
actuator broker.

The PC publishes the absolute destination immediately. The ESP's existing
50 Hz acceleration- and velocity-limited interpolation controls the physical
trajectory, preserving fluid motion. Manual control retains its three-second
lease and forces fresh two-frame face acquisition afterward.

Frames captured or processed during a body pivot or settling interval remain
observation-only and cannot update the gaze estimator or publish a head target.

## Body Pivot Interaction

A newly calculated head target must be allowed to move before body-pivot
authorization. Body pivot confirmation uses persistent residual image error or
measured actual head offset after the head correction, not the size of the
just-issued desired target.

The existing 1.5-second confirmation, bounded pivot duration, one-second
settling period, and five-second opposite-direction block remain unchanged.

## Status and Diagnostics

Extend tracking samples and `/tracking/status` with:

- fresh normalized eye midpoint
- horizontal and vertical angular error
- actual head position used as the calculation origin
- calculated absolute head target
- residual angular error on the next fresh detection
- whether actual telemetry or acknowledged fallback position was used

These are numeric values only. No image bytes are logged or journaled.

## Tests

Unit tests cover:

- centered eyes producing no command
- a face at `x = 0.90` producing approximately 25.7 degrees of pan correction
- symmetric left/right and up/down corrections
- absolute targets originating from actual telemetry
- acknowledged-position fallback when telemetry is unavailable
- servo-range clamping
- configurable calibration gains and signs
- angular deadband behavior
- initial acquisition bypassing lagging temporal smoothing
- residual correction after the first move
- no estimator or command update during pivot settling
- manual override requiring fresh acquisition
- the actuator broker retaining its 4 Hz tracking cap

Existing face association, shadow isolation, loss behavior, endpoint, and full
PC Brain suites remain regression gates.

## Acceptance

In an attended test with a stationary visible face:

- acquisition still requires two consistent detections
- the first post-acquisition head command is issued from fresh eye geometry
- the face enters the angular deadband within one primary head movement plus at
  most one residual correction
- no unnecessary body pivot occurs while the face can be centered within the
  servo range
- physical head movement remains acceleration-limited and visually fluid
- tracking publishes no more than four head targets per second

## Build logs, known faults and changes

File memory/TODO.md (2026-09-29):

# memory — knowledge-graph memory (Pi Long Task TODO)

Converted from `memory/Plan.md`. Work through the TODOs in order; do not re-plan this file. Make reasonable implementation decisions yourself; keep it a working MVP.

## Context

HouseGremlin needs durable semantic memory for autonomous agents: a SQLite-backed knowledge graph under `memory/` where agents add facts (entity nodes, fact/claim nodes with provenance, typed edges). Retrieval finds an entrance node via hybrid search (FTS5 + optional embeddings), then an LLM router hops through the graph to assemble bounded context. Every retrieval is logged as training data for a future learned router.

New component mirrors `brain/` / `tracking/` layout: FastAPI service on **port 8092**, SQLite WAL DB under `memory/data/`, OpenAI-compatible LLM client (pattern from `brain/app/llm.py`). Ports: 8080=brain, 8081=llama-server, 8091=tracking, 8092=memory.

## Mandatory corrections (non-negotiable; override Plan.md where they conflict)

1. **Windows PowerShell only — never bash.** All shell steps are PowerShell commands run from repo root `C:\dev\HouseGremlin`.
2. **`memory` must be a proper package with no ambiguous `app` imports.** Create `memory/__init__.py` and `memory/app/__init__.py`; every internal import is absolute `from memory.app.<mod> import ...`. Root `pytest.ini` becomes `pythonpath = . brain` (repo root resolves the `memory` package; do NOT add bare `memory` to pythonpath — that would make `import app` ambiguous with `brain/app`).
3. **Contradictory facts coexist.** On a `contradiction` verdict, link the two fact nodes with `contradicted_by` edges and keep both active. Do NOT reduce a fact's confidence merely because it is older (overrides Plan.md's "lower the older fact's confidence").
4. **Hard rendered-context budget.** Context assembly enforces a hard size budget (`MEMORY_CONTEXT_BUDGET_CHARS`, default 6000) and drops lowest-relevance nodes until under budget. Test this explicitly.
5. **Fact/assertion nodes are the canonical representation of claims.** Every claim lives on a `fact` node (sentence + confidence + ≥1 provenance row). Entity↔entity triple edges link entities to their fact node; edges do not carry claims by themselves.
6. **FTS5 stays synchronized.** The FTS5 external-content table over `nodes.text` must be kept in sync on every node insert/update/delete (SQLite triggers or equivalent app-level writes), plus a `rebuild` CLI command that re-syncs FTS + vector index from source rows.

## Operational rules

- Preserve existing HouseGremlin functionality; this work is additive under `memory/` plus the one-line root `pytest.ini` change.
- Keep implementations simple and MVP-focused; no speculative features.
- Run relevant tests after each phase (`pytest memory/tests -q` from repo root); fix failures before moving on. Never retry the same failing approach more than twice — change tack or record the blocker.
- Commit completed working phases as checkpoints (PowerShell `git add` / `git commit`).
- LLM endpoints: default llama-server at `http://127.0.0.1:8081/v1`. If 8081 is down, try `http://127.0.0.1:8888/v1` (unsloth server) for chat; embeddings may be unavailable → the FTS5-only path must work and `/health` must report the mode. All unit tests use a mocked LLM (deterministic JSON), never a live model.
- If genuinely blocked on a TODO: save current work, keep the repo clean/recoverable, mark that TODO's Status items honestly, continue with later TODOs where possible, and record the blocker + exact next step in `tmp/BLOCKER.md`.

## TODO 1 — Phase 0: scaffold memory package

**Goal:** Create the proper Python package skeleton with config and DB schema so `pytest memory/tests` runs green from the repo root.

**Status:**

- [x] Create `memory/__init__.py`, `memory/app/__init__.py`; every internal import is absolute `from memory.app.<mod> import ...` — no bare `app` imports anywhere under `memory/`.
- [x] `requirements.txt` pinned like `brain/requirements.txt`: fastapi, uvicorn[standard], httpx, pydantic, python-dotenv, numpy, ddgs, beautifulsoup4, pytest.
- [x] `app/config.py`: frozen dataclass Settings with `MEMORY_*` env settings (port 8092, DB path under `memory/data/`, LLM base URL default `http://127.0.0.1:8081/v1`, model name, context budget chars, max hops, beam), dotenv loading; mirror the `brain/app/config.py` pattern.
- [x] `app/db.py`: SQLite WAL connection helper + schema init (nodes, edges, provenance, retrieval_traces, url_cache) + FTS5 external-content table over `nodes.text` with sync triggers on insert/update/delete + `rebuild_fts()` helper.
- [x] Root `pytest.ini` → `pythonpath = . brain`; add `memory/pytest.ini` (`pythonpath = ..`) mirroring `brain/pytest.ini`.
- [x] README stub, `.gitignore` entry for `memory/data/*.db*`, smoke test that imports `memory.app.config` and initializes the schema in a temp DB.

**Verify:**

- [x] From repo root (PowerShell): `pytest memory/tests -q` is green.
- [x] No file under `memory/` contains a bare `from app` / `import app` import.

**Done when:** Package imports cleanly as `memory.app.*`, schema + FTS5 init works in a temp DB, smoke test passes from the repo root.

## TODO 2 — Phase 1: core store with dedup/merge and forget cascade

**Goal:** Node/edge/provenance upserts, LLM-verdict dedup/merge with contradiction coexistence, forget cascade, inspect/stats; tests green.

**Status:**

- [x] `app/store.py`: upsert node (entity/fact), typed edge insert (unique `(src, dst, type)`), provenance attach. Fact nodes are canonical claims (correction 5): every claim is a `fact` node with sentence/confidence/≥1 provenance; triple edges link subject/object entities to the fact node.
- [x] Dedup/merge: exact-normalized entity match; for facts, candidate search via FTS5 (+ embedding cosine when available); LLM verdict prompt returning strict JSON `duplicate | related | contradiction | new`. Duplicate → merge (keep oldest id, raise confidence, add provenance). Contradiction → `contradicted_by` edges between the two fact nodes, both stay active, no age-based confidence change (correction 3). Never silent overwrite.
- [x] Forget cascade: delete node → its edges → its provenance + FTS5 rows; inspect/stats queries.
- [x] Tests: schema init, entity dedup merge, fact duplicate merge, contradiction flagging (both facts survive with `contradicted_by`), forget cascade leaves FTS consistent.

**Verify:**

- [x] From repo root: `pytest memory/tests -q` is green.
- [x] No code path lowers confidence solely because a fact is older.

**Done when:** All Phase 1 store tests pass from the repo root with a mocked LLM verdict client.

## TODO 3 — Phase 2: ingestion pipeline (LLM extraction + web)

**Goal:** LLM/embed clients, strict-JSON extraction, web search/fetch, `POST /facts` + `/ingest/text` + `/ingest/url` endpoints and CLI equivalents; mocked-LLM tests green.

**Status:**

- [x] `app/llm.py`: OpenAI-compatible chat client (pattern from `brain/app/llm.py`), strict-JSON prompt style, `think: false`, temperature ~0.2, one retry on parse failure.
- [x] `app/embed.py`: `/v1/embeddings` client with graceful unavailability (returns None; service degrades to FTS5-only and `/health` reports the mode).
- [x] `app/extract.py`: extraction prompt → pydantic models (triples, fact sentences, edge types); invalid LLM output rejected and logged — never partial writes.
- [x] `app/search.py`: ddgs DuckDuckGo query → top-N URLs → httpx fetch → BeautifulSoup text; per-URL cache table; rate-limited; skip-and-continue on failure.
- [x] `app/main.py` FastAPI app + endpoints: `POST /facts`, `POST /ingest/text`, `POST /ingest/url`, `GET /health` (reports embedding mode), `GET /stats`; `app/cli.py` argparse CLI: `add-fact`, `ingest-text`, `ingest-url`, `inspect`, `stats`, `health`.
- [x] Tests with a mocked LLM (deterministic JSON) and a recorded HTML fixture; no live-model tests.

**Verify:**

- [x] From repo root: `pytest memory/tests -q` is green.
- [x] Live-service smoke (PowerShell): start uvicorn on 8092, `POST /facts` one fact, `GET /stats` shows it, stop the service.

**Done when:** Ingestion endpoints work end-to-end in tests with a mocked LLM and pass the live-service smoke test.

## TODO 4 — Phase 3: routed retrieval with trace logging

**Goal:** FTS5+cosine seeds → RRF fusion → hop router (≤3 hops, beam ≤6) → budgeted context assembly + trace logging; `POST /retrieve` + CLI + seed script; tests green.

**Status:**

- [x] `app/retrieve.py`: seeds = FTS5 lexical scores + embedding cosine (when available) → RRF fusion → top-k entrance nodes. Router loop `max_hops=3`, beam ≤6: candidates = typed edge neighbors of visited set ∪ embedding-similar unvisited nodes; LLM returns strict JSON chosen node ids with one-line reasons or `stop`; early-stop on `stop`. (FTS seeds filter stopwords so function words can't pollute the seed set.)
- [x] Context assembly: visited nodes ordered by hop/relevance → compact text blocks (node text + edge types to neighbors); enforce the hard rendered-context budget (`MEMORY_CONTEXT_BUDGET_CHARS`, default 6000) by dropping lowest-relevance nodes until under budget (correction 4). Return both structured JSON and a rendered context string.
- [x] Every run writes a `retrieval_traces` row: question, seed ids, per-hop decisions (candidates/chosen/reason), visited ids, rendered context, optional feedback — training-ready schema.
- [x] `POST /retrieve` `{question, max_hops?, beam?}` → `{context, nodes[], trace_id}`; `GET /traces/{id}`; CLI `retrieve` (+ `seed`).
- [x] Seed script: hand-built sky-is-blue causal chain (sky → Rayleigh scattering → short-wavelength scatter) + distractor facts — idempotent (`app/seed.py`, CLI `seed`).
- [x] Tests: seed ranking, hop budget enforcement, early stop, trace completeness, FTS5-only fallback when embeddings unavailable, context-budget truncation, seed idempotency (9 tests in `tests/test_retrieve.py`).

**Verify:**

- [x] From repo root: `pytest memory/tests -q` is green (33 passed).
- [x] CLI `retrieve "why is the sky blue"` on the seeded DB returns context containing the causal chain within budget (verified; degrades to seed-only with a stderr warning when the live LLM at 8081 is down).

## TODO 5 — Phase 4: learned-router groundwork (design-for-now)

**Goal:** Trace export, curated question set, evaluation harness stub for future LLM-vs-learned router A/B. No training code until traces accumulate.

**Status:**

- [x] Trace export helper: CSV/JSONL of question → visited path; CLI `export-traces`. (`app/traces.py`: `load_traces` + `export_traces` with full-fidelity JSONL and flat CSV.)
- [x] Curated question set (≥10 questions, multi-hop included) as JSON under `memory/evals/`. (`evals/questions.json`: 12 questions over the sky chain + distractors; `full-chain` requires ≥3 expected facts across hops.)
- [x] Evaluation harness stub that scores returned context against expected key facts for LLM router vs learned router A/B (learned side is a documented placeholder). (`app/eval.py`: `score_context` case-insensitive substring scoring, `run_eval` over the curated set; `router="learned"` raises `NotImplementedError` with a pointer to `retrieval_traces` until a model is trained.)

**Verify:**

- [x] From repo root: `pytest memory/tests -q` is green (41 passed).
- [x] `export-traces` produces a non-empty file from the seeded DB (verified both `jsonl` and `csv` on a scratch DB).

**Done when:** Traces export cleanly, curated set + harness stub are in place, tests pass.

## TODO 6 — Docs, end-to-end verification, final checkpoint

**Goal:** README complete, DESIGN.md updated, full test suite green (including brain regression), e2e run with live LLM if available, repo committed and clean.

**Status:**

- [x] `memory/README.md`: quickstart, endpoints, env vars, agent usage examples, CLI walkthrough.
- [x] Update `DESIGN.md` memory section: memory is the graph substrate Gate 4 semantic memory builds on; note the deliberate pivot from "RAG before GraphRAG" for this component (added under "RAG before GraphRAG").
- [x] Full suite from repo root: `pytest memory/tests -q` → 41 passed; `pytest brain/tests -q` → 118 passed (regression check; required installing Pillow into the shared venv — pre-existing missing dependency, not a regression).
- [x] E2E: no live LLM available (8081 down; 8888 up but requires an API key and none is configured) → **e2e mock-verified**: seeded DB + keyword-plan router walks seeds `[1,4,5]` → hop 1 picks node 2 ("rayleigh") → hop 2 picks node 3 ("wavelength") → visited `[1,4,5,2,3]`; context 1027/6000 chars contains the full causal chain; trace row shows seeds → per-hop decisions → visited.
- [x] Curated set check: **11/12** questions fully answered (all expected facts in context) with a deterministic token-overlap router — ≥10 required. Sole miss: `octopus-probe` ("Is there anything stored about octopuses?") — plural "octopuses" does not lexically match the node text "octopus" (FTS5 has no stemming); a discriminating probe, expected to fail on the lexical path.
- [x] Forget test: deleted a distractor node → node gone, 0 edges / 0 provenance rows left, `rebuild_fts` leaves fts_rows == nodes_rows (7 == 7).
- [x] Manual: `GET /health` → `{"status":"ok","embedding_mode":"fts5_only"}`, `GET /stats` shows the seeded graph on port 8092; final checkpoint committed.

**Verify:**

- [x] `git status` clean (only intentional untracked artifacts: `memory/.gitkeep`, `plans/`), all tests green, e2e evidence recorded above.

**Done when:** Docs complete, all tests green, e2e evidence recorded, repo committed and recoverable.

## Progress

- [x] TODO 1 — Phase 0: scaffold memory package
- [x] TODO 2 — Phase 1: core store with dedup/merge and forget cascade
- [x] TODO 3 — Phase 2: ingestion pipeline (LLM extraction + web)
- [x] TODO 4 — Phase 3: routed retrieval with trace logging
- [x] TODO 5 — Phase 4: learned-router groundwork (design-for-now)
- [x] TODO 6 — Docs, end-to-end verification, final checkpoint

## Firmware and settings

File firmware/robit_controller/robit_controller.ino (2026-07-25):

#include "camera.h"
#include "control_channel.h"
#include "eyes.h"
#include "motors.h"
#include "robot_state.h"
#include "servos.h"
#include "wifi_control.h"

void setup() {
  Serial.begin(115200);
  delay(50);
  Serial.println("[BOOT] Robit starting");

  initializeState();
  initializeMotors();
  initializeServos();
  initializeEyes();
  initializeCamera();
  initializeWifi();
  initializeControlChannel();
  initializeHttpServer();
}

void loop() {
  updateWifi();
  updateControlChannel();
  updateHttpServer();
  updateMotors();
  updateServos();
  updateEyes();
  updateCamera();
  enforceSafetyTimeouts();
}

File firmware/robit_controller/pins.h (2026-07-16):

#pragma once

#include <Arduino.h>

// Tracks. Both motor-driver PWM inputs are soldered to D4.
constexpr uint8_t LEFT_FWD_PIN = D0;
constexpr uint8_t LEFT_REV_PIN = D1;
constexpr uint8_t RIGHT_FWD_PIN = D2;
constexpr uint8_t RIGHT_REV_PIN = D3;
constexpr uint8_t MOTOR_PWM_PIN = D4;

// PCA9685 servo controller.
constexpr uint8_t SERVO_SDA_PIN = D6;
constexpr uint8_t SERVO_SCL_PIN = D7;
constexpr uint8_t SERVO_PCA9685_ADDRESS = 0x40;
constexpr uint8_t SERVO_PAN_CHANNEL = 0;
constexpr uint8_t SERVO_TILT_CHANNEL = 1;

// Eye OLEDs share the PCA9685 I2C bus. Their addresses do not conflict with
// each other or with the servo controller at 0x40.
constexpr uint8_t EYES_SDA_PIN = SERVO_SDA_PIN;
constexpr uint8_t EYES_SCL_PIN = SERVO_SCL_PIN;
constexpr uint8_t EYES_LEFT_OLED_ADDRESS = 0x3C;
constexpr uint8_t EYES_RIGHT_OLED_ADDRESS = 0x3D;

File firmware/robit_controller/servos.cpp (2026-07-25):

#include "servos.h"

#include <Adafruit_PWMServoDriver.h>
#include <Wire.h>

#if __has_include("config.h")
#include "config.h"
#else
#include "config.example.h"
#endif

#include "pins.h"
#include "robot_state.h"

namespace {
Adafruit_PWMServoDriver pwm(SERVO_PCA9685_ADDRESS);
int currentPanAngle = 90;
int currentTiltAngle = 90;
float currentPanPosition = 90.0f;
float currentTiltPosition = 90.0f;
int targetPanAngle = 90;
int targetTiltAngle = 90;
float panVelocityDegreesPerSecond = 0.0f;
float tiltVelocityDegreesPerSecond = 0.0f;
unsigned long lastServoUpdateAt = 0;

#ifndef PAN_SERVO_MIN_PULSE
#define PAN_SERVO_MIN_PULSE 80
#endif

#ifndef PAN_SERVO_MAX_PULSE
#define PAN_SERVO_MAX_PULSE 620
#endif

#ifndef PAN_SERVO_CENTER_TRIM_DEGREES
#define PAN_SERVO_CENTER_TRIM_DEGREES 0
#endif

#ifndef PAN_SERVO_INVERT
#define PAN_SERVO_INVERT 0
#endif

#ifndef HEAD_PAN_MAX_SPEED_DPS
#define HEAD_PAN_MAX_SPEED_DPS 90.0f
#endif

#ifndef HEAD_TILT_MAX_SPEED_DPS
#define HEAD_TILT_MAX_SPEED_DPS 70.0f
#endif

#ifndef HEAD_SERVO_ACCELERATION_DPS2
#define HEAD_SERVO_ACCELERATION_DPS2 240.0f
#endif

#ifndef HEAD_SERVO_UPDATE_INTERVAL_MS
#define HEAD_SERVO_UPDATE_INTERVAL_MS 20
#endif

#ifndef TILT_SERVO_MIN_PULSE
#define TILT_SERVO_MIN_PULSE 80
#endif

#ifndef TILT_SERVO_MAX_PULSE
#define TILT_SERVO_MAX_PULSE 620
#endif

#ifndef TILT_SERVO_CENTER_TRIM_DEGREES
#define TILT_SERVO_CENTER_TRIM_DEGREES 0
#endif

#ifndef TILT_SERVO_INVERT
#define TILT_SERVO_INVERT 0
#endif

int calibratedAngle(int angle, int trimDegrees, bool invert) {
  int calibrated = constrain(angle + trimDegrees, 0, 180);
  return invert ? 180 - calibrated : calibrated;
}

int angleToPulse(int angle, int minPulse, int maxPulse, int trimDegrees, bool invert) {
  return map(calibratedAngle(angle, trimDegrees, invert), 0, 180, minPulse, maxPulse);
}

void writeServo(uint8_t channel, int angle, int minPulse, int maxPulse, int trimDegrees, bool invert) {
  pwm.setPWM(channel, 0, angleToPulse(angle, minPulse, maxPulse, trimDegrees, invert));
}

void writePanServo(int angle) {
  writeServo(
    SERVO_PAN_CHANNEL,
    angle,
    PAN_SERVO_MIN_PULSE,
    PAN_SERVO_MAX_PULSE,
    PAN_SERVO_CENTER_TRIM_DEGREES,
    PAN_SERVO_INVERT != 0
  );
}

void writeTiltServo(int angle) {
  writeServo(
    SERVO_TILT_CHANNEL,
    angle,
    TILT_SERVO_MIN_PULSE,
    TILT_SERVO_MAX_PULSE,
    TILT_SERVO_CENTER_TRIM_DEGREES,
    TILT_SERVO_INVERT != 0
  );
}

float easedStepToward(
  float current,
  int target,
  float& velocityDegreesPerSecond,
  float maximumSpeedDegreesPerSecond,
  float deltaSeconds
) {
  const float distance = static_cast<float>(target - current);
  if (fabsf(distance) < 0.01f) {
    velocityDegreesPerSecond = 0.0f;
    return target;
  }

  const float direction = distance > 0.0f ? 1.0f : -1.0f;
  const float brakingSpeed = sqrtf(
    2.0f * HEAD_SERVO_ACCELERATION_DPS2 * fabsf(distance)
  );
  const float desiredSpeed = direction * min(maximumSpeedDegreesPerSecond, brakingSpeed);
  const float maximumVelocityChange = HEAD_SERVO_ACCELERATION_DPS2 * deltaSeconds;
  if (velocityDegreesPerSecond < desiredSpeed) {
    velocityDegreesPerSecond = min(
      velocityDegreesPerSecond + maximumVelocityChange,
      desiredSpeed
    );
  } else {
    velocityDegreesPerSecond = max(
      velocityDegreesPerSecond - maximumVelocityChange,
      desiredSpeed
    );
  }

  const float step = velocityDegreesPerSecond * deltaSeconds;
  if (fabsf(step) >= fabsf(distance)) {
    velocityDegreesPerSecond = 0.0f;
    return target;
  }
  return current + step;
}
}

bool initializeServos() {
  Wire.begin(SERVO_SDA_PIN, SERVO_SCL_PIN);
  pwm.begin();
  pwm.setPWMFreq(50);
  delay(250);
  currentPanAngle = targetPanAngle = robotState.panAngle = 90;
  currentTiltAngle = targetTiltAngle = robotState.tiltAngle = 90;
  currentPanPosition = 90.0f;
  currentTiltPosition = 90.0f;
  panVelocityDegreesPerSecond = 0.0f;
  tiltVelocityDegreesPerSecond = 0.0f;
  writePanServo(currentPanAngle);
  writeTiltServo(currentTiltAngle);
  Serial.println("[SERVO] PCA9685 initialized at 0x40");
  return true;
}

void setPanAngle(int angle) {
  targetPanAngle = constrain(angle, PAN_MIN, PAN_MAX);
  robotState.panAngle = targetPanAngle;
}

void setTiltAngle(int angle) {
  targetTiltAngle = constrain(angle, TILT_MIN, TILT_MAX);
  robotState.tiltAngle = targetTiltAngle;
}

void setHeadPosition(int pan, int tilt) {
  setPanAngle(pan);
  setTiltAngle(tilt);
}

void moveHeadRelative(int panDelta, int tiltDelta) {
  setHeadPosition(robotState.panAngle + panDelta, robotState.tiltAngle + tiltDelta);
}

void centerHead() {
  setHeadPosition(90, 90);
}

void updateServos() {
  const unsigned long now = millis();
  if (now - lastServoUpdateAt < HEAD_SERVO_UPDATE_INTERVAL_MS) return;
  const unsigned long elapsedMs = lastServoUpdateAt == 0
    ? HEAD_SERVO_UPDATE_INTERVAL_MS
    : now - lastServoUpdateAt;
  lastServoUpdateAt = now;
  const float deltaSeconds = min(elapsedMs, 100UL) / 1000.0f;

  currentPanPosition = easedStepToward(
    currentPanPosition,
    targetPanAngle,
    panVelocityDegreesPerSecond,
    HEAD_PAN_MAX_SPEED_DPS,
    deltaSeconds
  );
  currentTiltPosition = easedStepToward(
    currentTiltPosition,
    targetTiltAngle,
    tiltVelocityDegreesPerSecond,
    HEAD_TILT_MAX_SPEED_DPS,
    deltaSeconds
  );
  const int nextPanAngle = roundf(currentPanPosition);
  const int nextTiltAngle = roundf(currentTiltPosition);
  if (nextPanAngle != currentPanAngle) {
    currentPanAngle = nextPanAngle;
    writePanServo(currentPanAngle);
  }
  if (nextTiltAngle != currentTiltAngle) {
    currentTiltAngle = nextTiltAngle;
    writeTiltServo(currentTiltAngle);
  }
}

int getActualPanAngle() {
  return currentPanAngle;
}

int getActualTiltAngle() {
  return currentTiltAngle;
}

int getTargetPanAngle() {
  return targetPanAngle;
}

int getTargetTiltAngle() {
  return targetTiltAngle;
}

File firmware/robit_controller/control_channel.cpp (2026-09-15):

#include "control_channel.h"

#include <WiFi.h>

#if __has_include("config.h")
#include "config.h"
#else
#include "config.example.h"
#endif

#include "eyes.h"
#include "motors.h"
#include "robot_state.h"
#include "servos.h"
#include "telemetry_serialization.h"

namespace {
constexpr size_t MAX_CONTROL_MESSAGE_BYTES = 512;
constexpr size_t MAX_CONTROL_SESSION_BYTES = 48;

#ifndef ROBIT_CONTROL_TCP_PORT
#define ROBIT_CONTROL_TCP_PORT 82
#endif
#ifndef ROBIT_CONTROL_TELEMETRY_INTERVAL_MS
#define ROBIT_CONTROL_TELEMETRY_INTERVAL_MS 500
#endif
#ifndef ROBIT_CONTROL_HEARTBEAT_TIMEOUT_MS
#define ROBIT_CONTROL_HEARTBEAT_TIMEOUT_MS 3000
#endif

WiFiServer controlServer(ROBIT_CONTROL_TCP_PORT);
WiFiClient controlClient;
String inputBuffer;
String activeSession;
unsigned long lastAcceptedSequence = 0;
unsigned long lastControlMessageAt = 0;
unsigned long lastTelemetryAt = 0;
bool handshakeComplete = false;
bool telemetryDirty = true;
String lastObservedMovement = "";
String lastObservedEyes = "";
int lastObservedPanTarget = -1;
int lastObservedTiltTarget = -1;

String jsonEscape(const String& value) {
  String escaped;
  escaped.reserve(value.length());
  for (size_t index = 0; index < value.length(); index++) {
    const char valueCharacter = value[index];
    if (valueCharacter == '"' || valueCharacter == '\\') escaped += '\\';
    escaped += valueCharacter;
  }
  return escaped;
}

String jsonStringValue(const String& source, const String& key, const String& fallback = "") {
  const String needle = "\"" + key + "\"";
  const int keyIndex = source.indexOf(needle);
  if (keyIndex < 0) return fallback;
  const int colonIndex = source.indexOf(':', keyIndex + needle.length());
  if (colonIndex < 0) return fallback;
  const int startQuote = source.indexOf('"', colonIndex + 1);
  if (startQuote < 0) return fallback;
  const int endQuote = source.indexOf('"', startQuote + 1);
  if (endQuote < 0) return fallback;
  return source.substring(startQuote + 1, endQuote);
}

long jsonLongValue(const String& source, const String& key, long fallback) {
  const String needle = "\"" + key + "\"";
  const int keyIndex = source.indexOf(needle);
  if (keyIndex < 0) return fallback;
  const int colonIndex = source.indexOf(':', keyIndex + needle.length());
  if (colonIndex < 0) return fallback;
  int start = colonIndex + 1;
  while (start < source.length() && isspace(source[start])) start++;
  int end = start;
  while (end < source.length() && (isdigit(source[end]) || source[end] == '-')) end++;
  if (end == start) return fallback;
  return source.substring(start, end).toInt();
}

unsigned long jsonUnsignedLongValue(
  const String& source,
  const String& key,
  unsigned long fallback
) {
  const String needle = "\"" + key + "\"";
  const int keyIndex = source.indexOf(needle);
  if (keyIndex < 0) return fallback;
  const int colonIndex = source.indexOf(':', keyIndex + needle.length());
  if (colonIndex < 0) return fallback;
  int start = colonIndex + 1;
  while (start < source.length() && isspace(source[start])) start++;
  int end = start;
  while (end < source.length() && isdigit(source[end])) end++;
  if (end == start) return fallback;
  return strtoul(source.substring(start, end).c_str(), nullptr, 10);
}

void sendLine(const String& payload) {
  if (!controlClient || !controlClient.connected()) return;
  if (payload.length() >= MAX_CONTROL_MESSAGE_BYTES) {
    Serial.printf(
      "[CONTROL][ERROR] refusing oversized outbound message bytes=%u\n",
      static_cast<unsigned int>(payload.length())
    );
    return;
  }
  controlClient.print(payload);
  controlClient.print('\n');
}

robit::telemetry::StateSnapshot controlStateSnapshot() {
  robit::telemetry::StateSnapshot snapshot;
  snapshot.movement = robotState.movement.c_str();
  snapshot.speed = robotState.motorSpeed;
  snapshot.pan = robotState.panAngle;
  snapshot.tilt = robotState.tiltAngle;
  snapshot.pan_actual = getActualPanAngle();
  snapshot.tilt_actual = getActualTiltAngle();
  snapshot.pan_target = getTargetPanAngle();
  snapshot.tilt_target = getTargetTiltAngle();
  snapshot.eyes = robotState.eyeExpression.c_str();
  snapshot.wifi_rssi = WiFi.status() == WL_CONNECTED ? WiFi.RSSI() : 0;
  snapshot.camera_enabled = robotState.cameraEnabled;
  snapshot.heartbeat_armed = isBrainHeartbeatArmed();
  snapshot.heartbeat_fault = isBrainHeartbeatFaultActive();
  snapshot.uptime_ms = millis();
  snapshot.wifi_mode = robotState.apFallback ? "ap" : "sta";
  snapshot.heap_free_bytes = ESP.getFreeHeap();
  snapshot.heap_min_free_bytes = ESP.getMinFreeHeap();
  snapshot.heap_total_bytes = ESP.getHeapSize();
  // ESP32 reports zero for these values if PSRAM is unsupported.
  snapshot.psram_free_bytes = ESP.getFreePsram();
  snapshot.psram_total_bytes = ESP.getPsramSize();
  snapshot.control_last_receive_age_ms = controlLastReceiveAgeMs();
  return snapshot;
}

String compactStateJson(bool includeHealth = false) {
  const robit::telemetry::StateSnapshot snapshot = controlStateSnapshot();
  const std::string json = includeHealth
    ? robit::telemetry::telemetryStateJson(snapshot)
    : robit::telemetry::legacyStateJson(snapshot);
  return String(json.c_str());
}

void sendAck(unsigned long sequence, const String& status, const String& detail = "") {
  String json = "{\"v\":1,\"type\":\"ack\",\"session\":\"" + jsonEscape(activeSession) + "\"";
  json += ",\"seq\":" + String(sequence);
  json += ",\"status\":\"" + jsonEscape(status) + "\"";
  if (detail.length() > 0) json += ",\"detail\":\"" + jsonEscape(detail) + "\"";
  json += ",\"state\":" + compactStateJson() + "}";
  sendLine(json);
}

void sendTelemetry() {
  const robit::telemetry::StateSnapshot snapshot = controlStateSnapshot();
  const std::string packet = robit::telemetry::telemetryPacketJson(
    activeSession.c_str(), lastAcceptedSequence, snapshot
  );
  sendLine(String(packet.c_str()));
  lastTelemetryAt = millis();
  telemetryDirty = false;
  lastObservedMovement = robotState.movement;
  lastObservedEyes = robotState.eyeExpression;
  lastObservedPanTarget = getTargetPanAngle();
  lastObservedTiltTarget = getTargetTiltAngle();
}

void resetConnection(bool stopBody) {
  if (stopBody) stopMotors();
  if (controlClient) controlClient.stop();
  inputBuffer = "";
  activeSession = "";
  lastAcceptedSequence = 0;
  lastControlMessageAt = 0;
  handshakeComplete = false;
  telemetryDirty = true;
}

void acceptNewClient() {
  if (controlClient && controlClient.connected()) return;
  WiFiClient candidate = controlServer.available();
  if (!candidate) return;
  resetConnection(true);
  controlClient = candidate;
  controlClient.setNoDelay(true);
  lastControlMessageAt = millis();
}
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

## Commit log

2026-07-11 Added stl files
    [Robit(41).stl, Robit(42).stl, Robit(43).stl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]
2026-07-12 Camera working and ip set
2026-07-14 Gate 1 passed and improved UI some camera bus issues
2026-07-25 docs: design calibrated angular gaze controller
2026-07-25 docs: plan calibrated angular gaze implementation
2026-09-10 feat: extend ESP32 telemetry health
2026-09-15 feat: phase 2: ingestion pipeline (LLM extraction + web), endpoints, CLI, thread-safe service
2026-09-15 feat: phase 3: routed retrieval (FTS5+embedding seeds, RRF, LLM hop router), trace logging, seed corpus
2026-09-15 feat: phase 4: trace export (JSONL/CSV) + CLI, curated eval set, A/B harness stub; fix pre-existing pyright errors
2026-09-15 docs: phase 5 — full README, DESIGN.md pivot note, e2e mock-verified + final checkpoint
2026-09-17 feat(pc_memory): telemetry ingestion driver + autonomous web researcher
    Two growth loops so the memory graph fills itself while you're away.
    Phase 4b — robot telemetry → graph (zero-LLM, VRAM-safe):
    - app/brain_ingest.py: reads pc_brain/data/brain.db read-only, turns each
    brain_event into a stable claim sentence deterministically (no timestamps,
    so repeats merge), stores via store.add_fact with provenance
    source_kind='manual'/source_ref='brain_event:<id>'. Per-event idempotency
    via already_ingested() on source_ref — a crash/state-reset can't double-count.
    - CLI: ingest-brain (one-shot, --dry-run, --no-embed) + watch-brain (--poll-seconds).
    Phase 4c — autonomous web research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
2026-09-29 chore: remove dead files, tool state, and orphaned scripts (reorg phase 1)
    Sweep of vibe-coding residue, all verified zero-reference before removal:
    - Untrack .superpowers/ tool state (stale server PID/token + brainstorm HTML mockups); gitignore it.
    - Remove pc_brain/app/cuda_paths.py (no callers).
    - Remove Scripts/patch_speech_to_speech_timeout.py (one-shot, already applied in 92e3917).
    - Remove YuNet face-tracking plan (0/44 tasks, zero code refs — superseded by RF-DETR path).
    - Remove 3 streaming-spike WAV artifacts and 4 orphaned dev scripts.
    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
